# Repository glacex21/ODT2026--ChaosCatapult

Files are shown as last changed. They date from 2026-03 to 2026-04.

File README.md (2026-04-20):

# Open Design and Technology  
## Final Project README

> **Project Weight:** 70%  
> **Team Size:** 2 students  
> **Project Duration:** 4 weeks  
> **Class Time Available:** 6 hours per class  
> **Total Time Available:** 48 effort-hours per team  
> **Project Type:** Playful, interactive, technology-based experience

---

# Before you begin

## Fork and rename this repository
After forking this repository, rename it using the format:

`ODT-2026-TeamName`

### Example
`ODT-2026-PixelWizards`

Do not keep the default repository name.

---

# How to use this README

This file is your team’s **working project document**.

You must keep updating it throughout the 4-week build period.  
By the final review, this README should clearly show:
- your idea,
- your planning,
- your design decisions,
- your technical process,
- your build progress,
- your testing,
- your failures and changes,
- your final outcome.

## Rules
- Fill every section.
- Do not delete headings.
- If something does not apply, write `Not applicable` and explain why.
- Add images, screenshots, sketches, links, and videos wherever useful.
- Update task status and weekly logs regularly.
- Use this file as evidence of process, not only as a final report.

---

# 1. Team Identity

## 1.1 Studio / Group Name
`Group 15 - Chaos Catapult`

## 1.2 Team Members

| Name | Primary Role | Secondary Role | Strengths Brought to the Project |
|---|---|---|---|
| `Abhinav Akhare` | `Ideation/ Electronics / Coding / App / Mechanics` | `Fabrication` | `Strong understanding of mechanisms, hands-on prototyping, and integrating electronics with physical systems through iterative testing.` |
| `Riddhi Piratwad` | `-` | `-` | `-` |

## 1.3 Project Title
`Chaos Catapult`

## 1.4 One-Line Pitch
`A sensor-triggered, motorized catapult that combines controlled mechanics with unpredictable outcomes, creating a repeatable yet chaotic play experience.`

## 1.5 Expanded Project Idea
In 1–2 paragraphs, explain:
- what your project is,
- what kind of playful experience it creates,
- what makes it fun, curious, engaging, strange, satisfying, competitive, or delightful,
- what technologies are involved.

**Response:**  
`The Chaos Catapult is a motorized, sensor-driven kinetic system designed to transform simple user input into dynamic launch actions. The project is built around a seesaw-like catapult mechanism, where a controlled sequence of motor movements—combined with a gated release system—creates a repeatable launching process. An IR sensor detects user interaction, triggering a programmed sequence that rewinds, locks, and releases the mechanism, resulting in the projection of an object.
The experience is designed to be playful and engaging through the contrast between control and unpredictability. While the system operates through precise electronic and mechanical coordination, the outcome of each launch varies based on factors like weight, placement, and timing, making every interaction slightly different. This creates a sense of anticipation and satisfaction, encouraging repeated use. The project integrates multiple technologies, including an ESP32 microcontroller, DC and stepper motors for motion control, sensor-based triggering, and LED feedback, all working together to produce a responsive and interactive physical system.`

---

# 2. Philosophy Fit

## 2.1 Experience, Not Social Problem
This module does **not** require your project to solve a large social problem.

You are allowed to build:
- toys,
- games,
- interactive objects,
- playful machines,
- kinetic artifacts,
- humorous devices,
- strange but delightful experiences,
- things that are entertaining to use or watch.

## 2.2 What kind of experience are you creating?
Answer the following:
- What is the experience?
- What do you want the player or participant to feel?
- Why would someone want to try it again?

**Response:**  
`The project creates a playful, interactive experience centered around cause-and-effect, where a simple user action triggers a chain of mechanical and electronic responses leading to a launch. It functions as a kinetic, game-like object that invites users to engage with it physically and observe the outcome. The experience is less about winning or scoring and more about interaction, anticipation, and observing how the system responds.
The intended feeling is a mix of curiosity, anticipation, and satisfaction. Users experience a build-up as the system prepares to launch, followed by a sudden release, which creates a sense of excitement. Since the outcome of each launch can vary based on small changes in input—such as object placement or timing—the interaction feels unpredictable and slightly chaotic.
Users are encouraged to try it repeatedly because each interaction can produce a different result. This variability, combined with the satisfying mechanical motion and responsive feedback, makes the system engaging and replayable, turning a simple action into an enjoyable and dynamic experience.`

## 2.3 Design Persona
Complete the sentence below:

> We are designing this project as if we are a small creative studio making a **[toy / game / playable object / interactive experience]** for **[children / teens / adults / classmates / exhibition visitors / mixed audience]**.

**Response:**  
`We are designing this project as if we are a small creative studio making a playful, chaos-driven interactive object for classmates and exhibition visitors who like experimenting and figuring things out.`

---

# 3. Inspiration

## 3.1 References
List what inspired the project.

| Source Type | Title / Link | What Inspired You |
|---|---|---|
| `[Toy` | `Traditional Catapult / Trebuchet` | `Influenced the idea of launching objects through stored and released energy, creating a playful and physics-based interaction.` |
| `Game / Interaction` | `Arcade Trigger-Based Games` | `Inspired the simple input → action → response loop, where a user action immediately triggers a dynamic system reaction.` |

## 3.2 Original Twist
What makes your project original?

**Response:**  
`The project reinterprets a traditional catapult by shifting it from a purely manual mechanism to a partially automated, sensor-driven system. Instead of relying on direct human force, the interaction is mediated through a sequence of electronic and mechanical actions, including motorised actuation and controlled release through a gated mechanism. This introduces a layer of system logic between input and output, transforming a simple physical action into a multi-stage interactive process. What makes the project distinct is the combination of precise control and unpredictable outcomes. While the system is designed to operate through programmed sequences and controlled motion, the final result of each launch varies due to physical factors such as weight distribution, timing, and alignment. This tension between control and variability creates a unique play experience that blends engineered precision with emergent behaviour.`

---

# 4. Project Intent

## 4.1 Core Interaction Loop
Describe the main loop of interaction.

Examples:
- press → launch → score → reset
- connect → control → observe → repeat
- turn → trigger → react → repeat
- move object → sensor detects → sound/light response → player reacts

**Response:**  
`system ready → platform opens → weight drops → motor rewinds mechanism → IR sensor detects position → motor stops → gate closes to hold weight → motor releases (launch action) → system resets to initial state → repeat`

## 4.2 Intended Player / Audience

| Question | Response |
|---|---|
| Who is this for? | `Students & Peers` |
| Age range | `12+` |
| Solo or multiplayer | `Primarily solo, but can be observed and enjoyed by multiple people` |
| Expected duration of one round | `10-15 seconds per cycle` |
| What should the player feel? | `Curiosity, anticipation, and satisfaction from the launch action` |
| Is explanation required before use? | `Minimal explanation required; interaction is mostly intuitive with basic guidance` |

## 4.3 Player Journey
Describe exactly how a player will use the project.

1. **Approach:** `The player approaches the setup, noticing the catapult mechanism and multiple target cups placed at increasing distances.`
2. **Start:** `The player connects to the system through the app and prepares the catapult for use.`
3. **First Action:** `The player places a ball on the platform and uses the app to trigger the system.`
4. **Main Interaction:** `The system runs its sequence—opening the platform, rewinding the mechanism, and preparing for launch—while the player observes and anticipates the outcome.`
5. **System Response:** `The mechanism releases, launching the ball toward the target. The result varies based on placement, timing, and system dynamics.`
6. **Win / Lose / End Condition:** `If the ball lands in the target cup, the player successfully completes that level. If the player misses, they must move the catapult forward (using the wheeled base) to attempt the next target at a different distance.`
7. **Reset:** `The system resets to its initial state, allowing the player to reposition, place another ball, and attempt the next level.`

## 4.4 Rules of Play
If your project is a game, list the rules clearly.

- `The player must place a ball on the catapult platform before triggering the system.`
- `The system can only be activated through the app once the setup is ready.`
- `The objective is to land the ball inside the target cup.`
- `If the player misses, they must reposition the catapult using the wheeled base and attempt the next level.`
 - `Each successful shot allows progression to a farther or more challenging target.`
 - `The system must complete its full cycle (launch and reset) before the next attempt begins.`
---

# 5. Definition of Success

## 5.1 Definition of “Playable”
Your project will be considered complete only if these conditions are met.

- [x] `[The system responds to user input (app or sensor) and initiates the sequence]`
- [x] `[he mechanical system is able to perform the launch action]`
- [ ] `[The motor-driven rewind and release mechanism functions with partial or full consistency]`
- [x] `[The gate mechanism successfully controls the holding and release of the object]`
- [ ] `[The system is able to reset to an initial or near-initial state for repeated interaction]`

## 5.2 Minimum Viable Version
What is the smallest version of this project that still delivers the core experience?

**Response:**  
`The minimum viable version of the project focuses on achieving a partially automated interaction where the system responds to input and executes key stages of the sequence, even if the final actuation is inconsistent.

In this version, components such as sensor detection, sequencing logic, and control of intermediate stages like gate movement function as intended, demonstrating the designed interaction flow. However, the main motor-driven launch may not perform reliably due to hardware limitations.

This still allows the core idea of a staged, system-driven interaction to be understood, where user input triggers a chain of mechanical and electronic responses, even if the final output is not fully realized.`

## 5.3 Stretch Features
What features are nice to have but not essential?

- `Automated scoring system to track successful shots into the target`
- `Adjustable launch power or angle control through the app`
- `Multiple difficulty levels with dynamic target positions or distances`
---

# 6. System Overview

## 6.1 Project Type
Check all that apply.

- [x] Electronics-based
- [x] Mechanical
- [x] Sensor-based
- [x] App-connected
- [x] Motorized
- [ ] Sound-based
- [ ] Light-based
- [ ] Screen/UI-based
- [x] Fabricated structure
- [x] Game logic based
- [x] Installation / tabletop experience
- [ ] Other: `[Write here]`

## 6.2 High-Level System Description
Explain how the system works in simple terms.

Include:
- input,
- processing,
- output,
- physical structure,
- app interaction if any.

**Response:**  
`The project is a multi-stage interactive system that combines electronics, mechanical movement, and programmed logic to create a controlled launching mechanism. At its core, the system is designed so that a simple user input triggers a sequence of coordinated actions rather than a single direct response.
The interaction begins when the system receives input, either through an IR sensor detecting the presence or position of an object, or through a mobile app used to initiate the sequence. This input is processed by the ESP32 microcontroller, which acts as the central control unit. Based on the programmed logic, the ESP32 executes a step-by-step sequence that coordinates multiple components instead of activating them all at once. The system output is achieved through a combination of motors and visual feedback. A stepper motor controls the opening and closing of a gate mechanism, which determines when the object is held or released. A DC motor drives the rewind and release motion of the catapult, creating the force required for launching. LEDs are used to communicate system states, such as readiness, active motion, and completion, helping the user understand what stage the system is in. Physically, the project is built as a wheeled catapult structure with a pivot-based mechanism. The platform holds the object initially, and through the sequence of actions, the object is repositioned and eventually launched. The inclusion of wheels allows the entire system to be repositioned in space, enabling different levels or target distances as part of the gameplay.
The mobile app acts as an interface layer between the user and the system, allowing control over when the sequence begins and potentially adjusting how the system behaves. Overall, the project integrates input, processing, and output into a coordinated system where mechanical movement and electronic control work together to produce a dynamic and repeatable interaction.`

## 6.3 Input / Output Map

| System Part | Type | What It Does |
|---|---|---|
| IR Sensor | Input | Detects the presence or position of the weight/ball and signals the system to proceed with the sequence |
| Mobile App | Input | Allows the user to trigger and control the system remotely |
| ESP32 | Processing | Acts as the central controller, executing the programmed sequence and coordinating all components |
| Step-Up Converter  | Processing / Power | Regulates and boosts voltage to provide sufficient power for motors, ensuring stable operation |
| Motor Driver | Processing / Control | Interfaces between ESP32 and motors, controlling direction and power delivery |
| DC Motor | Output | Drives the rewind and release mechanism responsible for the launching action |
| Stepper Motor | Output | Controls precise opening and closing of the gate mechanism |
| LEDs | Output | Provide visual feedback for system states (ready, active, rewinding, reset) |
| Catapult Mechanism | Physical Action | Converts rotational motion into a launching force through a pivot-based system |
| Gate Mechanism | Physical Action | Holds and releases the object at the correct stage of the sequence |
| Wheeled Base | Physical Action | Allows repositioning of the system for level-based gameplay | NEMA 17 Stepper Motor | Output | Provides precise control for rewind and release |

---

# 7. Sketches and Visual Planning

## 7.1 Concept Sketch
Add an early sketch of the full idea.

**Insert image below:**  
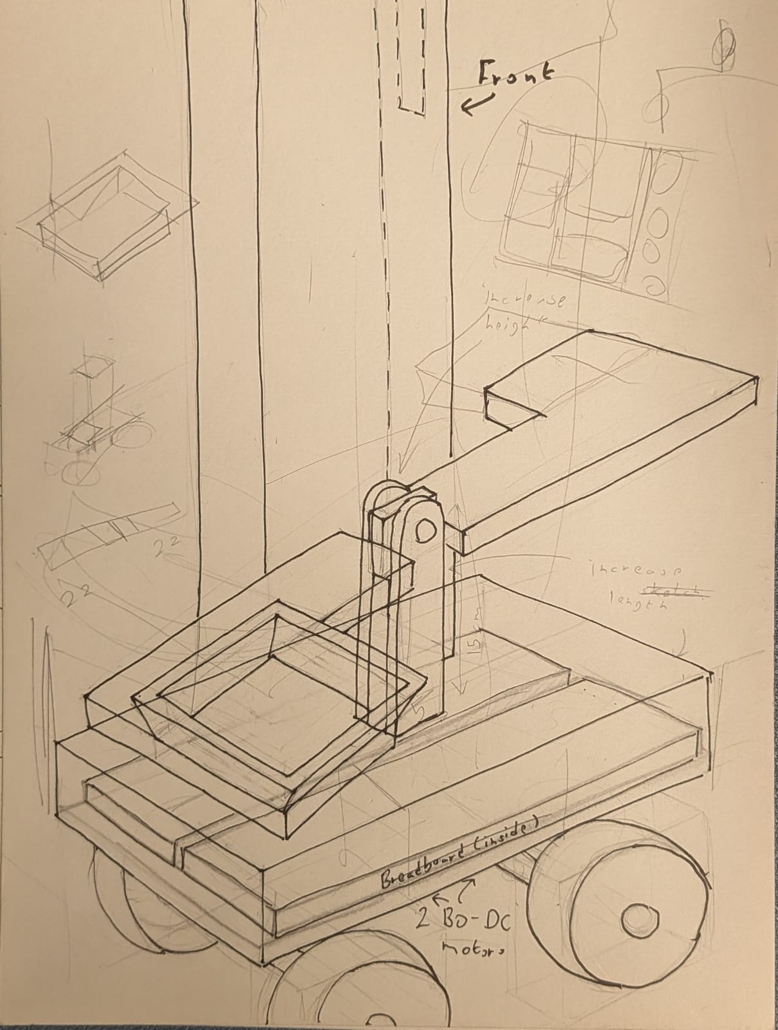
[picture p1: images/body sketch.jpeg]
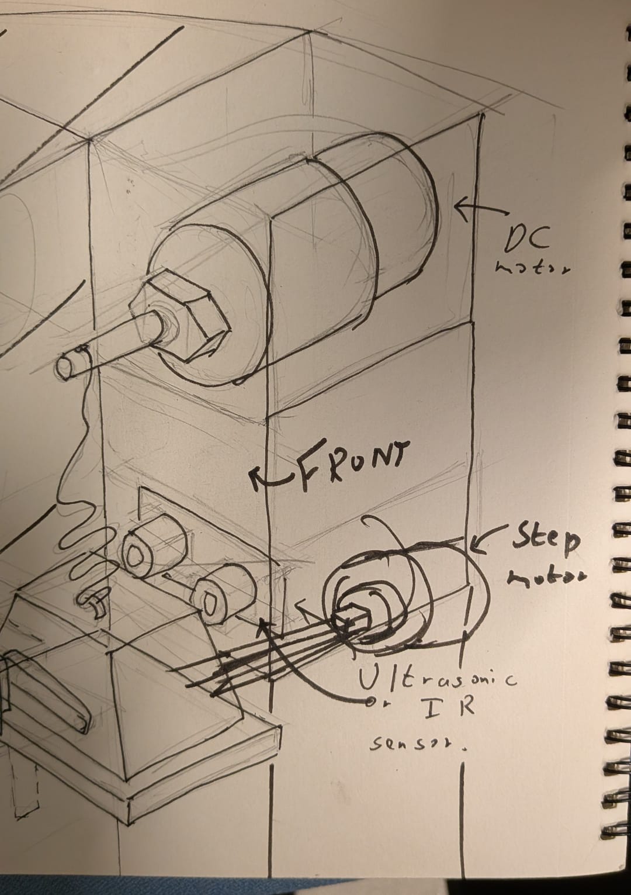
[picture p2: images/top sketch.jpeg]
 

## 7.2 Labeled Build Sketch
Add a sketch with labels showing:
- structure,
- electronics placement,
- user touch points,
- moving parts,
- output elements.

**Insert image below:**  
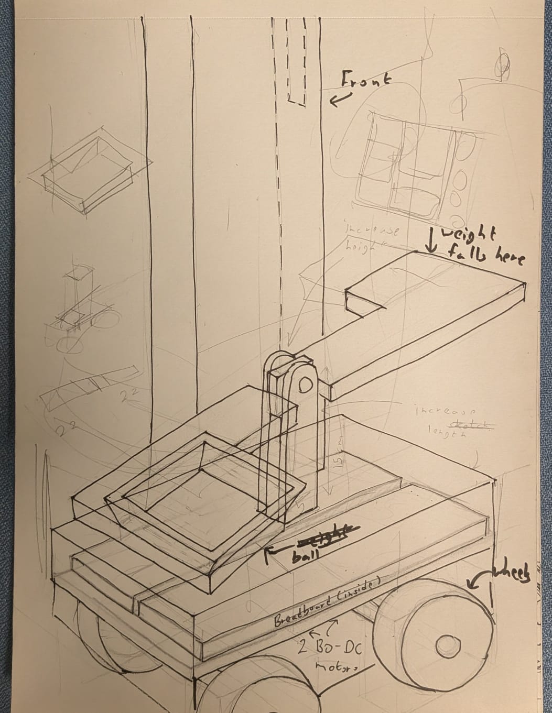
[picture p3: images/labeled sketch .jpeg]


## 7.3 Approximate Dimensions

| Dimension | Value |
|---|---|
| Length | `40cm` |
| Width | `[25cm]` |
| Height | `[50cm]` |
| Estimated weight | `[400-500gms]` |

---

# 8. Mechanical Planning

## 8.1 Mechanical Features
Check all that apply.

- [ ] Gears
- [x] Pulleys
- [ ] Belt drives
- [ ] Linkages
- [x] Hinges
- [x] Shafts
- [ ] Springs
- [ ] Bearings
- [x] Wheels
- [ ] Sliders
- [x] Levers
- [ ] Not applicable

## 8.2 Mechanical Description
Describe the mechanism and what it is meant to do.

**Response:**  
`[The mechanical system is based on a lever-driven catapult mechanism, where a pivot point allows rotational motion to be converted into a launching action. A platform holds the object initially, and through controlled movement, the system transfers force to propel the object forward.
A pulley system is integrated with the motor to lift and rewind the weight. As the motor rotates, the pulley winds a string or linkage, pulling the mechanism into a loaded position. This allows energy to be stored and later released during the launch phase.
A gate mechanism is used to control when the object is released. This gate is actuated using a stepper motor, allowing precise opening and closing at specific stages of the sequence.
During development, the initial DC motor showed inconsistent performance during the rewind stage, including irregular motion and unreliable operation under load. To address this, a NEMA 17 stepper motor was introduced as an alternative, as it provides better control and more consistent torque for lifting and positioning the mechanism.
The entire system is mounted on a wheeled base, allowing it to be repositioned for different target distances and levels. The combination of lever mechanics, pulley-based lifting, and motor-driven control creates a staged and interactive mechanical system.]`

## 8.3 Motion Planning
If something moves, explain:
- what moves,
- what causes the movement,
- how far it moves,
- how fast it moves,
- what could go wrong.

**Response:**  
`The main moving parts are the catapult arm, the pulley system, the gate, and the wheels. The catapult arm rotates around a pivot to create the launch. The pulley system lifts the weight during rewind, and the gate opens and closes to control when the object is released. The wheels allow the system to move forward and backward for positioning.
The movement is caused by motors. A DC motor is used for the rewind and release mechanism through the pulley, while a NEMA 17 stepper motor was tested as an alternative. A separate stepper motor controls the gate movement. BO DC motors are used to drive the wheels for movement.
The gate moves roughly 90°, and the catapult arm moves through a small arc to generate the launch. The rewind motion is slower and controlled, while the release is faster to create force. Wheel movement is continuous and depends on motor input.
Possible issues include low torque in the DC motor during rewind, insufficient performance from the NEMA setup, pulley misalignment, stepper jamming, and instability due to weight during movement. These issues affected the consistency of the full sequence.`

## 8.4 Simulation / CAD / Animation Before Making
If your project includes mechanical motion, document the digital planning before fabrication.

| Tool Used | File / Link | What Was Tested |
|---|---|---|
| `Not Applicable]` | `-` | `[No simulation or animation was performed; the mechanism was developed through physical prototyping and testing` |

## 8.5 Changes After Digital Testing
What changed after the CAD, animation, or simulation stage?

**Response:**  
`Not applicable, as no digital simulation was used. Changes were made directly through physical testing and iteration during the build process.`

---

# 9. Electronics Planning

## 9.1 Electronics Used

| Component | Quantity | Purpose |
|---|---:|---|
| ESP32 | 1 | Main controller to process input and control the system |
| IR Sensor | 1 | Detects the presence/position of the object |
| BO DC Motors | 2 | Drive the wheels for movement of the system |
| DC Motor | 1 | Drives the rewind mechanism for lifting the weight |
| NEMA 17 Stepper Motor | 1 | Tested as an alternative for the rewind mechanism |
| Stepper Motor (Gate) | 1 | Controls opening and closing of the gate |
| Motor Drivers (L298N) | 2 | Control motor direction and power delivery |
| Step-Up Converters | 2 | Boost voltage (5V to ~8V) for motors |
| LEDs (Red & Green) | 2 | Provide visual feedback for system states |
| Power Bank | 1 | Supplies power to the entire system |

## 9.2 Wiring Plan
Describe the main electrical connections.

**Response:**  
`The system is powered using a power bank, which was modified to supply power through a step-up converter. The output from the step-up converter is connected to the power rails, which distribute power to the motors and other components.
The ESP32 is also powered through the power rails. A resistor-based connection is used along with a GPIO pin (keep_alive) to keep the power bank active continuously and prevent it from shutting off due to low current draw.
The IR sensor is connected to the ESP32, with power from the 3.3V pin and its output connected to a GPIO pin for input detection.
Motor control is handled using L298N motor drivers. The ESP32 is connected to the input pins (IN1, IN2, etc.) of the motor drivers to control motor direction. The enable pins are kept active or controlled via PWM depending on the requirement. One driver is used for the DC motor (and later testing with the NEMA 17), and another is used for additional motor control.
The motors are connected to the output terminals of the motor drivers, which receive power from the step-up converter to ensure sufficient voltage for operation under load.
LEDs are connected to GPIO pins on the ESP32 with resistors to provide visual feedback for different system states.
All components share a common ground through the power rails, ensuring stable communication and proper functioning of the system.`

## 9.3 Circuit Diagram
Insert a hand-drawn or software-made circuit diagram.

**Insert image below:**  
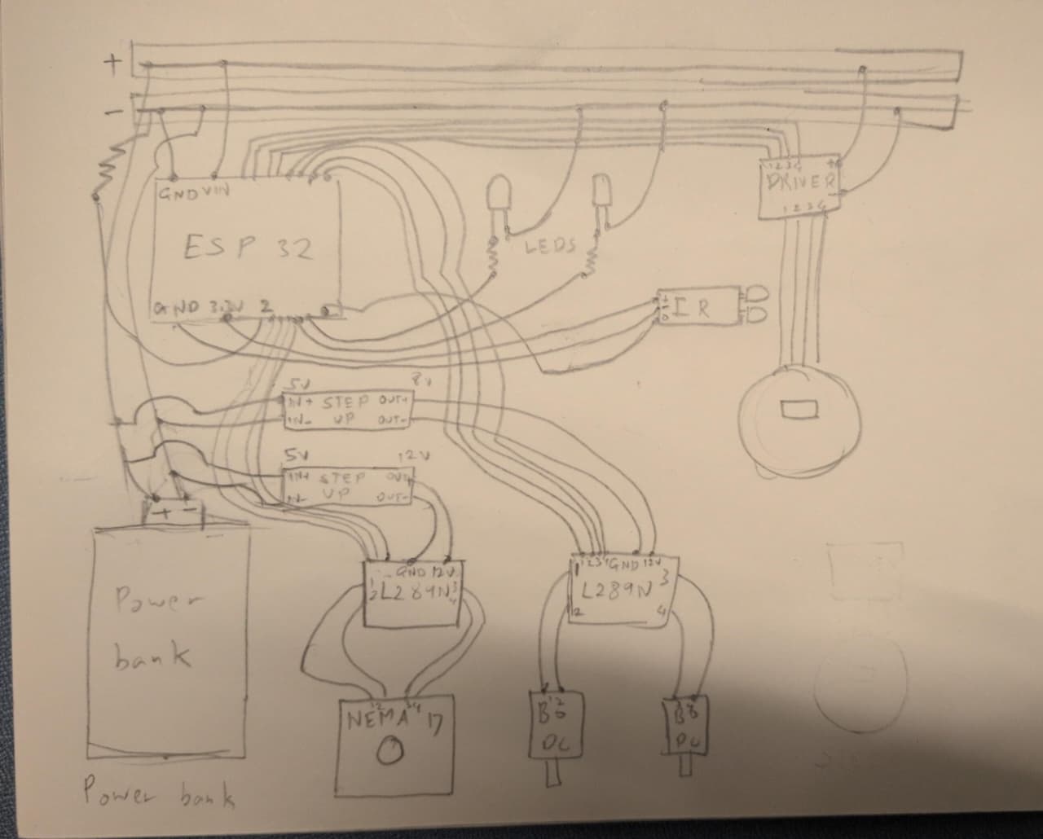
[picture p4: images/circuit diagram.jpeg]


## 9.4 Power Plan

| Question | Response |
| --- | --- |
| Power source | Power bank (USB-based) |
| Voltage required | 5V from power bank, stepped up to ~8V for motors using step-up converters |
| Current concerns | DC motor (used for rewind) and NEMA motor draw high current under load; BO DC motors for wheels also add load, causing unstable performance |
| Safety concerns  | Risk of overheating in motors and drivers, unstable voltage from converters, and loose wiring affecting reliability |

# 10. Software Planning

## 10.1 Software Tools

| Tool / Platform | Purpose |
| Tool / Platform                    | Purpose                                                                 |
| ---------------------------------- | ----------------------------------------------------------------------- |
| MicroPython                        | Used to program the ESP32 and control sensors, motors, and system logic |
| MIT App Inventor                   | Used to create a mobile app for triggering and controlling the system   |
|Thonny | Used to write, upload, and test code on the ESP32                       |

## 10.2 Software Logic
Describe what the code must do.

Include:
- startup behavior,
- input handling,
- sensor reading,
- decision logic,
- output behavior,
- communication logic,
- reset behavior.

**Response:**  
`The system is programmed using MicroPython on the ESP32 and follows a stage-based logic controlled through a mobile app.
At startup, all pins are initialized for motors, LEDs, and sensors, and the ESP32 connects to the app. The user sends commands like calibration, drop, close, rewind, and unwind through the app.
The system first runs in a manual calibration mode, where the gate position is adjusted using left/right controls. Once set, a “done” command locks the position.
After calibration, the system follows a sequence. A drop command opens the gate using the stepper motor. Then the rewind stage starts, where the mechanism is pulled back. In the DC motor version, this is done using continuous motor rotation, while in the NEMA stepper version, controlled stepping is used.
In the NEMA version, the rewind continues until the IR sensor detects the correct position, at which point the motor stops. This adds more control compared to the DC motor version.
A close command then shuts the gate to hold the weight. Finally, the unwind stage releases the stored energy, creating the launch action.
LEDs are used throughout to show system states like active movement, rewinding, and completion.
The system runs in a loop, constantly checking for app inputs and updating its state, allowing repeated cycles of interaction.`

## 10.3 Code Flowchart
Insert a flowchart showing your code logic.

Suggested sequence:
- start,
- initialize,
- wait for input,
- read input,
- decision,
- trigger output,
- repeat or reset,
- error handling.

**Insert image below:**  
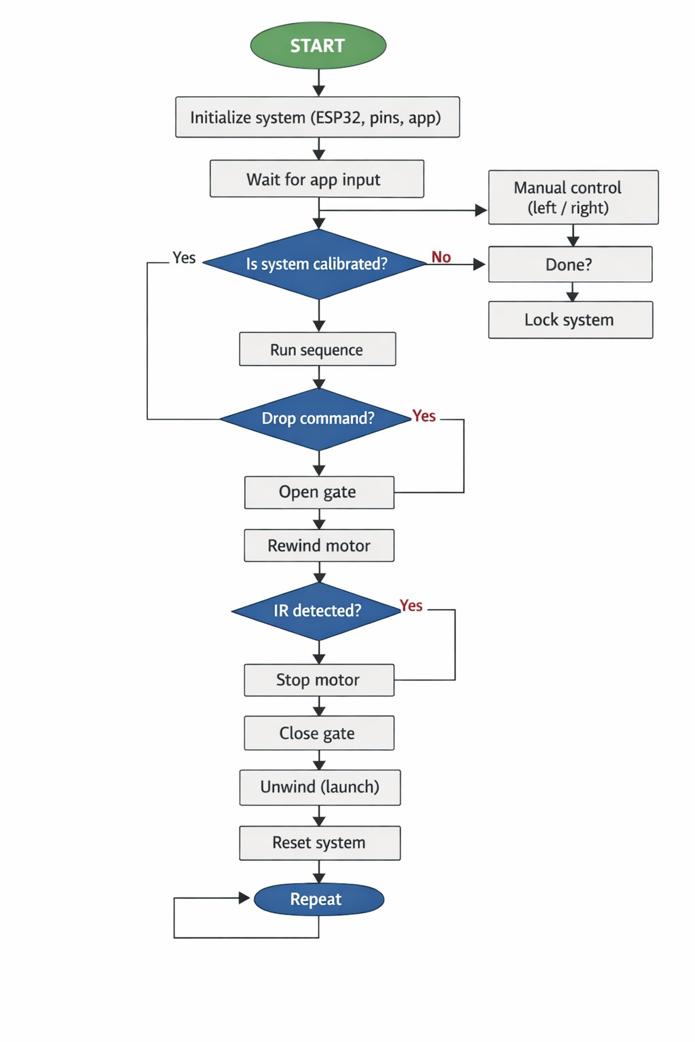
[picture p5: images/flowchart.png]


## 10.4 Pseudocode

```text
START

Initialize system (ESP32, pins, app)

WHILE true:
    Check for app input

    IF not calibrated:
        Allow manual gate control (left/right)
        IF user presses done:
            lock system

    ELSE:
        IF drop command:
            open gate

        IF rewind active:
            run motor
            IF IR detects position:
                stop motor

        IF close command:
            close gate

        IF unwind active:
            release mechanism (launch)

    Update LEDs based on state

END LOOP
```

---

# 11. MIT App Inventor Plan

## 11.1 Is an app part of this project?
- [x] Yes
- [ ] No

If yes, complete this section.

## 11.2 Why is the app needed?
Explain what the app adds to the experience.

Examples:
- remote control,
- score tracking,
- mode selection,
- personalization,
- triggering effects,
- displaying data.

**Response:**  
`The app is used to control and trigger the system wirelessly, allowing the user to interact with the catapult without directly touching the hardware. It enables actions such as calibration, opening and closing the gate, and controlling the rewind and release stages.
The app also allows movement control, enabling the system to move forward and backward for different levels or target distances. This adds flexibility to the interaction and supports the gameplay aspect.
Using the app makes the interaction more controlled and intuitive, as all actions are managed through a single interface instead of multiple physical inputs.`

## 11.3 App Features

| Feature | Purpose |
| --- | --- |
| Left / Right Control | Used during calibration to adjust gate position |
| Done Button | Locks the system after calibration is complete |
| Drop Button | Triggers opening of the gate to release the object |
| Close Button | Closes the gate to hold the object in place |
| Rewind Button | Activates motor to pull the mechanism back |
| Unwind Button | Releases the mechanism to perform the launch |
| Stop Button | Stops motor movement when required |
| Forward / Backward Control | Moves the system for level-based gameplay |

## 11.4 UI Mockup
Insert a sketch or screenshot of the app interface.

**Insert image below:**  
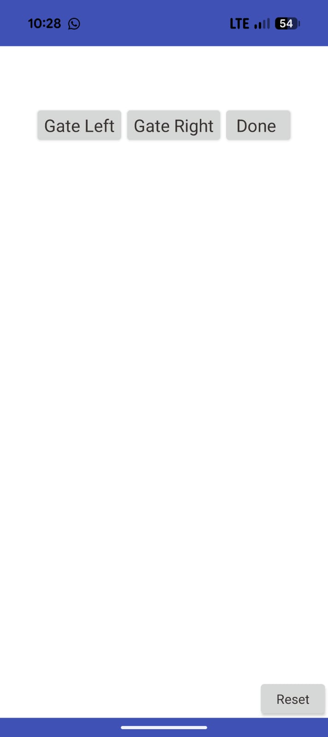
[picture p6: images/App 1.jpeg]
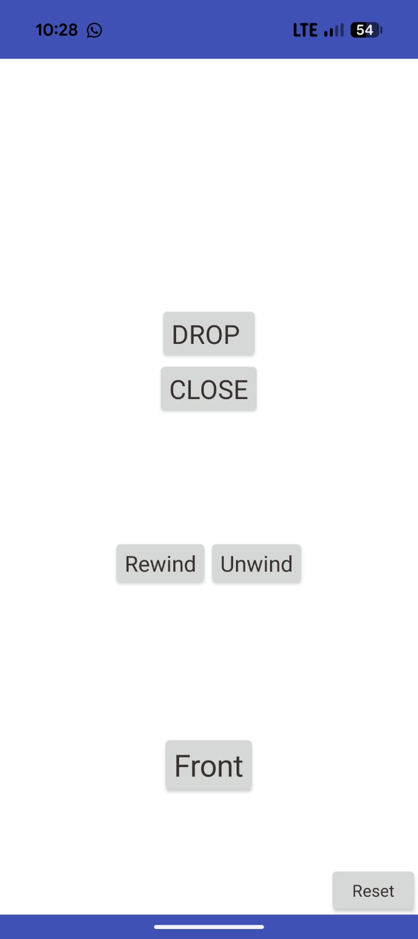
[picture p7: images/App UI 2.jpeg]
 

## 11.5 App Screen Flow

1. Open the app and access the control interface
2. Use left/right controls to calibrate the gate position
3. Press “Done” to lock the system in place
4. Use buttons like drop, rewind, close, and unwind to run the sequence
5. Use forward/backward controls to reposition the system for different levels
6. Repeat the process for each attempt
---

# 12. Bill of Materials

## 12.1 Full BOM

| Item | Quantity | In Kit? | Need to Buy? | Estimated Cost | Material / Spec | Why This Choice? |
| --- | ---: | --- | --- | ---: | --- | --- |
| ESP32 | 1 | Yes | No | 0 | Microcontroller | Main controller for system logic |
| IR Sensor | 1 | Yes | No | 0 | Digital sensor | Detects object position |
| DC Motor | 2 | No | Yes | ₹150 | Standard DC motor | Used for rewind and motion |
| NEMA 17 Stepper Motor | 1 | Yes | No | 0 | Stepper motor | Tested for better torque and control |
| Stepper Motor (Gate)  | 1 | Yes | No | 0 | Stepper motor | Controls gate opening/closing |
| L298N Motor Driver | 2 | Yes | No | 0 | Motor driver module | Controls motor direction and power |
| Step-Up Converter | 1 | No | Yes | ₹100 | Voltage booster | Provides sufficient voltage to motors |
| Wheels | 2–4 | No | Yes | ₹150 | Plastic wheels | Enables movement for level-based gameplay |
| LEDs | 2 | Yes | No | 0 | Red & Green LEDs | Visual feedback |
| Resistors | Few | Yes | No | 0 | Standard | Used for LEDs and keep-alive circuit |
| Power Bank | 1 | Yes | No | 0 | 5V output | Main power source |
| Wires / Connectors | Many | Yes | No | 0 | Jumper wires | Electrical connections |
| Structural Material | — | Yes | No | 0 | MDF / board | Physical structure |
| NEMA 17 Stepper Motor | 1 | No | Yes | ₹500 | Stepper motor | Purchased as a replacement due to DC motor performance issues |

## 12.2 Material Justification
Explain why you selected your main materials and components.

Examples:
- Why acrylic instead of cardboard?
- Why MDF instead of 3D print?
- Why servo instead of DC motor?
- Why bearing instead of a plain shaft hole?

**Response:**  
`The main structure of the project is made using MDF and wood as they are strong, easily available, and suitable for building stable mechanical systems. These materials are easy to cut, assemble, and modify during testing, which was important for iterative prototyping.
MDF provides a flat and rigid surface for mounting components, while wood adds additional strength to areas requiring support. Compared to materials like cardboard, they offer better durability and can handle the load and movement of motors and the catapult mechanism.`

## 12.3 Items to Purchase Separately

| Item | Why Needed | Purchase Link | Latest Safe Date to Procure | Status |
| --- | --- | --- | --- | --- |
| DC Motors | For rewind and movement mechanism | — | Week 2 | Received |
| Step-Up Converter | To provide sufficient voltage for motors | — | Week 2 | Received |
| Wheels | To enable movement for level-based gameplay | — | Week 2 | Received |
| NEMA 17 Stepper Motor | Emergency purchase to replace DC motor due to performance issues | — | Week 4 | Received |

## 12.4 Budget Summary

| Budget Item | Estimated Cost |
| --- | ---: |
| Electronics | ₹650 |
| Mechanical parts | ₹150 |
| Fabrication materials | ₹100 |
| Purchased extras | ₹0 |
| Contingency | ₹0 |
| **Total** | **₹900** |

## 12.5 Budget Reflection
If your cost is too high, what can be simplified, removed, substituted, or shared?

**Response:**  
`Most of the components were selected appropriately for the project, but the main challenge was with motor performance. The emergency purchase of the NEMA 17 stepper motor increased the overall cost but did not fully resolve the issue.
In hindsight, a better motor driver or power management setup for the DC motor could have been a more effective solution instead of replacing the motor entirely. This highlights the importance of selecting the right control and power components early in the design process.`

---

# 13. Planning the Work

## 13.1 Team Working Agreement
Write how your team will work together.

Include:
- how tasks are divided,
- how decisions are made,
- how progress will be checked,
- what happens if a task is delayed,
- how documentation will be maintained.

**Response:**  
`The project was initially planned with different parts like mechanics, electronics, and coding. However, since all these parts were closely connected, most of the work was handled together to keep the system consistent.
Work was done through continuous testing and iteration. Decisions were made based on what worked during testing, and changes were made accordingly.
Progress was tracked by testing different parts of the system and updating the documentation alongside the build. Any issues or delays were handled during the process by adjusting the approach and trying alternative solutions.`

## 13.2 Task Breakdown

| Task ID | Task | Owner | Estimated Hours | Deadline | Dependency | Status |
| --- | --- | --- | ---: | --- | --- | --- |
| T1 | Finalize concept and interaction | Abhinav Akhare | 3 | Week 1 | None | Done |
| T2 | Create sketches and design planning | Abhinav Akhare | 4 | Week 1 | T1 | Done |
| T3 | Source components and finalize BOM  | Abhinav Akhare | 2 | Week 1 | T1 | Done |
| T4 | Test electronics (motors, sensors)  | Abhinav Akhare | 6 | Week 2 | T3 | Done |
| T5 | Build mechanical structure | Abhinav Akhare | 8 | Week 2 | T2 | Done |
| T6 | Develop and test control code | Abhinav Akhare | 10 | Week 3 | T4 | Done |
| T7 | Integrate system (hardware + code)  | Abhinav Akhare | 8 | Week 3 | T5, T6 | Done |
| T8 | Debug and refine system | Abhinav Akhare | 5 | Week 4 | T7 | Done |
| T9 | Documentation and final updates | Abhinav Akhare | 4 | Week 4 | T8 | In Progress |

## 13.3 Responsibility Split

| Area | Main Owner | Support Owner |
| --- | --- | --- |
| Concept and gameplay | Abhinav Akhare | — |
| Electronics | Abhinav Akhare | — |
| Coding | Abhinav Akhare | — |
| App | Abhinav Akhare | — |
| Mechanical build | Abhinav Akhare | — |
| Testing | Abhinav Akhare | — |
| Documentation | Abhinav Akhare | — |

---

# 14. Weekly Milestones

## 14.1 Four-Week Plan

### Week 1 — Plan and De-risk
Expected outcomes:
- [x] Idea finalized
- [ ] Core interaction decided
- [x] Sketches made
- [x] BOM completed
- [x] Purchase needs identified
- [x] Key uncertainty identified
- [ ] Basic feasibility tested

### Week 2 — Build Subsystems
Expected outcomes:
- [x] Electronics tests completed
- [x] CAD / structure planning completed
- [ ] App UI started if needed
- [x] Mechanical concept tested
- [x] Main subsystems partially working

### Week 3 — Integrate
Expected outcomes:
- [x] Physical body built
- [x] Electronics integrated
- [x] Code connected to hardware
- [ ] App connected if required
- [ ] First playable version exists

### Week 4 — Refine and Finish
Expected outcomes:
- [ ] Technical bugs reduced
- [ ] Playtesting completed
- [ ] Improvements made
- [x] Documentation completed
- [x] Final build ready

## 14.2 Weekly Update Log

| Week | Planned Goal | What Actually Happened | What Changed | Next Steps |
| --- | --- | --- | --- | --- |
| Week 1 | Finalize idea and planning | Idea and overall interaction were finalized; initial direction was clear | Focus was more on concept than detailed technical planning  | Begin building structure and gather components |
| Week 2 | Build and test subsystems  | Mechanical structure was developed and components were organized | Electronics setup was planned but not fully implemented yet | Start electronics integration and coding |
| Week 3 | Integration and coding | Coding and wiring were developed, and initial system integration was attempted | Motor behavior required further tuning and testing | Improve motor control and refine system |
| Week 4 | Final build and testing | Major system integration, coding updates, and component adjustments (including NEMA) were completed | Adjustments were made to improve performance and control | Finalize documentation and system explanation  |

---

# 15. Risks and Unknowns

## 15.1 Risk Register

| Risk | Likelihood | Impact | Mitigation / Response |
| --- | --- | --- | --- |
| DC motor not providing enough torque | High | High | Issue identified during testing; replacement with NEMA motor attempted late |
| NEMA motor driver not handling load properly | High | High | Limited time for proper tuning; basic testing done |
| Stepper motor jamming during operation | Medium | High | Observed during testing; likely due to alignment/load issues |
| IR sensor giving inconsistent readings | Medium | Medium | Position adjusted but readings remained unreliable |
| Wheels unable to support system weight | Medium | Medium | Movement was reduced to avoid overload |
| Power supply instability (power bank limits) | High | High | Step-up converter and keep-alive used, but limitations remained |
| Timing mismatch between stages | Medium | Medium | Minor adjustments in code, but full synchronization not achieved |
| Integration issues between components | High | High | Integration attempted late; limited time for full debugging |
| Platform shape causing instability and misalignment | Medium | High | Iterated on shape during build, but consistent alignment was difficult to achieve |

## 15.2 Biggest Unknown Right Now
What is the single biggest uncertainty in your project at this stage?

**Response:**  
`One of the main failures in the system was the rewind mechanism. Both the DC motor and later the NEMA 17 stepper motor struggled to pull the weight effectively through the pulley system. The DC motor showed inconsistent behavior and lacked sufficient torque under load, which caused unreliable movement.
To address this, a NEMA 17 motor was introduced, but it also faced issues due to driver limitations and insufficient torque delivery in the given setup. As a result, the system was unable to consistently lift and position the weight for the launch sequence.
Additional issues included the stepper motor jamming at times, inconsistent readings from the IR sensor, and instability caused by the shape of the platform, which affected alignment. The wheels also faced difficulty supporting the overall load during movement.
These failures highlighted challenges in motor selection, load handling, and overall system integration.`

---

# 16. Testing and Playtesting

## 16.1 Technical Testing Plan

| What Needs Testing | How You Will Test It | Success Condition |
| --- | --- | --- |
| App connection (WiFi/App link) | Connect phone to ESP32 network and send commands from app | Commands are received and printed/responded correctly |
| Mechanism movement | Run motors (DC/NEMA and stepper) through app commands | Motors move in correct direction and complete intended motion |
| Sensor behavior (IR) | Place/remove object in front of sensor and monitor response | Sensor reliably detects presence/absence and triggers logic |
| App communication | Send actions like drop, close, rewind, unwind from app | System responds correctly to each command without delay |

## 16.2 Playtesting Plan

| Question | How You Will Check |
| --- | --- |
| Do players understand what to do? | Observe if users can place the ball correctly and use the app controls (drop, rewind, close) without detailed instructions |
| Is the interaction satisfying? | Observe reactions during the launch attempt, especially the rewind → release sequence |
| Do players want another turn? | Check if users try to adjust position (using wheels) and attempt again after missing the target |
| Is the challenge balanced? | Test different distances of the cup and see if users can reasonably aim using repositioning |
| Is the response clear and immediate? | Observe if users understand system states through motor movement and LED feedback during each stage |

## 16.3 Testing and Debugging Log

| Date | Problem Found | Type | What You Tried | Result | Next Action |
| --- | --- | --- | --- | --- | --- |
| Week 4 | DC motor unable to pull weight consistently | Technical | Increased voltage using step-up converter and reduced load | Partly | Look into stronger motor option |
| Week 3 | IR sensor giving inconsistent readings | Technical | Adjusted sensor placement and tested multiple times | Partly | Improve positioning and stability |
| Week 4 | Stepper motor jamming during movement | Mechanical  | Checked alignment and reduced friction in mechanism | Partly | Refine alignment and reduce resistance |
| Week 3 | Wheels unable to support system weight | Mechanical  | Tested movement with reduced load | Partly | Improve wheel support or reduce weight |
| Week 4 | NEMA motor introduced but driver struggled under load | Technical | Tested NEMA with existing driver setup | Failed | Explore better driver or alternative setup |
| Post-exhibition | Full system integration not stable | Integration | Tested components individually and reviewed sequence | Partly | Improve power management and synchronization |

## 16.4 Playtesting Notes

| Tester  | What They Did | What Confused Them | What They Enjoyed | What You Will Change |
| --- | --- | --- | --- | --- |
| Baratth | Tried to operate the system and place the ball for launch | Had difficulty understanding how to correctly set and calibrate the gate position | Liked the idea of launching towards a target | Simplify the gate calibration process and make it more intuitive |

---

# 17. Build Documentation

## 17.1 Fabrication Process
Describe how the project was physically made.

Include:
- cutting,
- 3D printing,
- assembly,
- fastening,
- wiring,
- finishing,
- revisions.

**Response:**  
`The fabrication process started with a rough foam model to understand the proportions and basic working of the mechanism. This helped in figuring out the placement of components and overall structure before moving to final materials.
Based on this, measurements were taken alongside ideation and the main parts were laser cut using MDF. During assembly in the wood lab, several adjustments were made to improve alignment and fit, especially for the pivot and pulley system.
The structure was assembled using basic fastening methods like screws and joints. Some components, such as axle caps, were 3D printed to support the wheel mechanism and ensure proper fitting.
Electronics were integrated after the basic structure was ready. Wiring was done using power rails, with the power bank connected through a step-up converter. The power bank was modified and connected in a way that allowed continuous supply using a keep-alive setup.
Multiple revisions were made during the build process, especially to adjust alignment, improve movement, and integrate the motors properly. Final finishing involved securing components, organizing wiring, and making the system stable for testing.`

## 17.2 Build Photos
Add photos throughout the project.

Suggested images:
- early sketch,
- prototype,
- electronics testing,
- mechanism test,
- app screenshot,
- final build.

Example:
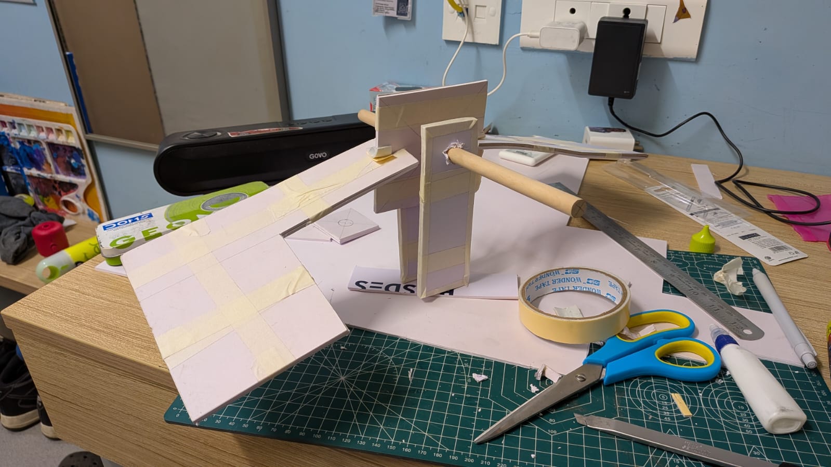
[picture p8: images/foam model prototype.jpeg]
 
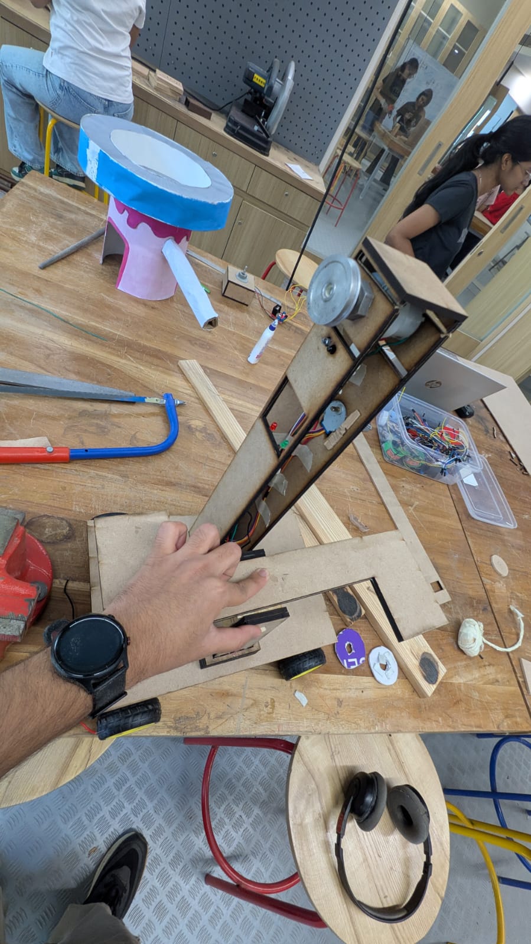
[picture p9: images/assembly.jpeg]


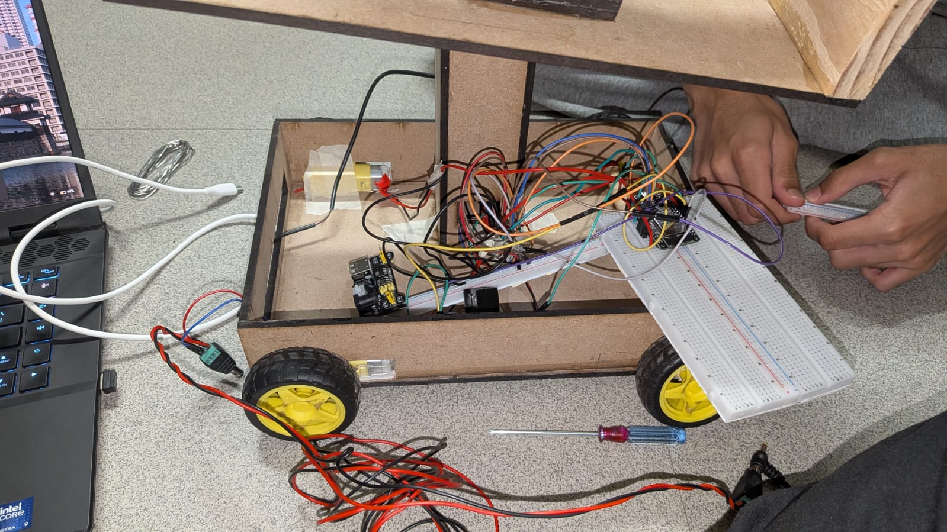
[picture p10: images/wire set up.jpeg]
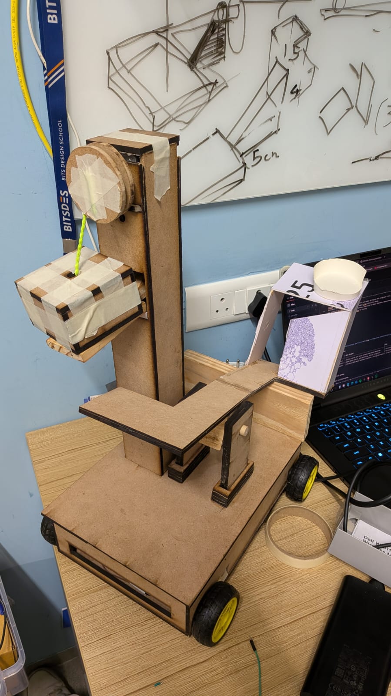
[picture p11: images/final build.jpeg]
 

## 17.3 Version History

| Version | Date | What Changed | Why |
| --- | --- | --- | --- |
| `v1` | Week 1 | Initial concept with basic catapult and manual mechanism | To establish core idea and interaction |
| `v2` | Week 2–3 | Added motor control, gate mechanism, and app integration | To automate the system and improve interaction |
| `v3` | Week 4 | Introduced NEMA motor and made structural + wiring adjustments | To address motor performance issues and improve load handling |

---

# 18. Final Outcome

## 18.1 Final Description
Describe the final version of your project.

**Response:**  
`The final version of the project is a motor-driven catapult system controlled through an app, combining a gate mechanism, pulley-based rewind system, and sensor-based logic. The system is designed to follow a sequence where the gate opens, the mechanism rewinds, and then releases to launch an object.
While individual parts like the app control, gate movement, and basic motor responses worked, the full system did not perform consistently due to issues with motor torque, load handling, and integration. However, the project demonstrates the intended interaction flow and system design.`

## 18.2 What Works Well
- `1. App control and command-based interaction works reliably
2. Gate mechanism using stepper motor functions as intended
3. Overall mechanical system (lever, pulley, structure) works well
4. Overall concept and interaction flow is clear and understandable`

## 18.3 What Still Needs Improvement
- `1. Motor system is not strong enough to handle the load consistently
2. Power and driver setup needs better optimization
3. Full system integration and synchronization between stages
4. Better alignment of pulley and platform to reduce resistance and jamming
5. More reliable sensor behavior (IR stability and accuracy)
6. Improved structural balance to support weight distribution (especially for wheels and movement)
7. Simplification of control flow to reduce dependency on multiple manual triggers`

## 18.4 What Changed From the Original Plan
How did the project change from the initial idea?

**Response:**  
`The initial idea was to create a fully automated catapult system where all stages—gate opening, rewind, detection, and release—would happen smoothly in a single sequence with minimal user input.
During development, the project evolved due to practical challenges with motor performance, load handling, and power supply. The system required more manual control through the app, and stages like rewind and release had to be triggered separately rather than running seamlessly.
There were also changes in components, such as replacing the DC motor with a NEMA stepper motor in an attempt to improve torque and control. Structural adjustments were made to the platform and pulley system to improve movement and alignment.
Overall, the project shifted from a fully automated system to a semi-controlled interactive system, focusing more on demonstrating the sequence and interaction rather than achieving perfect automation.`

---

# 19. Reflection

## 19.1 Team Reflection
What did your team do well?  
What slowed you down?  
How well did you manage time, tasks, and responsibilities?

**Response:**  
`The project was handled mostly individually, which helped maintain consistency across mechanics, electronics, and coding. Since all parts of the system were closely connected, working on everything together made it easier to make quick decisions and iterate without dependency on others. A lot of progress came from hands-on experimentation, testing components directly, and learning through trial and error.
What slowed things down was time management and late integration. Many components, especially motors and electronics, were brought together towards the end, which made debugging more difficult and limited the time available for proper testing. Earlier planning and prioritising critical systems like motor performance and power setup would have improved the overall workflow. Dividing time better between building, testing, and debugging would have made the process smoother.`

## 19.2 Technical Reflection
What did you learn about:
- electronics,
- coding,
- mechanisms,
- fabrication,
- integration?

**Response:**  
`This project helped in understanding how electronics, coding, and mechanical systems work together in a real setup rather than in isolation. Working with motors, drivers, and power systems showed how important torque, voltage, and current are, especially when dealing with load. It became clear that even if components work individually, they may not perform the same when integrated.
On the coding side, writing stage-based logic, handling app inputs, and integrating sensors was a useful learning experience. It also highlighted how hardware limitations directly affect software behavior. Fabrication and mechanisms were interesting to work on, especially combining lever motion with a pulley system to create a controlled action.
Overall, the biggest learning was how complex integration is, and how small issues in one part of the system can affect the entire workflow.`

## 19.3 Design Reflection
What did you learn about:
- designing for play,
- delight,
- clarity,
- physical interaction,
- player understanding,
- iteration?

**Response:**  
`The project showed that designing for play is not just about having an interesting idea, but about how clearly the interaction is understood by the user. Even though the concept was simple, the sequence of actions made it more engaging by adding anticipation and control.
It also became clear that too many steps or controls can confuse the user, especially when the system is not fully automated. Simplifying the interaction and reducing unnecessary steps would improve clarity. Physical interaction, such as moving the system and aiming, added an extra layer of engagement and made the experience more hands-on.
Iteration played a major role throughout the process, as multiple changes were made to both the structure and logic to improve how the system worked and felt.`

## 19.4 If You Had One More Week
What would you improve next?

**Response:**  
`With more time, the main focus would be on improving the motor and power system to make the launch sequence more reliable and consistent. This would include selecting better drivers, optimizing voltage supply, and reducing load on the mechanism.
I would also simplify the control flow so that the system runs more automatically instead of relying on multiple manual inputs. Earlier and more structured testing would be a priority, especially for load handling, motor performance, and full system integration.
Additionally, improvements in alignment, sensor stability, and overall finishing would help make the system more stable and user-friendly, resulting in a smoother and more polished experience.`

# 20. Final Submission Checklist

Before submission, confirm that:
- [x] Team details are complete
- [x] Project description is complete
- [x] Inspiration sources are included
- [x] Player journey is written
- [x] Sketches are added
- [x] BOM is complete
- [x] Purchase list is complete
- [x] Budget summary is complete
- [x] Mechanical planning is documented if applicable
- [x] App planning is documented if applicable
- [x] Code flowchart is added
- [x] Task breakdown is complete
- [x] Weekly logs are updated
- [x] Risk register is complete
- [x] Testing log is updated
- [x] Playtesting notes are included
- [x] Build photos are included
- [x] Final reflection is written

---

# 21. Suggested Repository Structure

```text
project-repo/
├── README.md
├── images/
│   ├── concept-sketch.jpg
│   ├── labeled-sketch.jpg
│   ├── circuit-diagram.jpg
│   ├── ui-mockup.jpg
│   ├── prototype-1.jpg
│   └── final-build.jpg
├── code/
│   ├── main.py
│   ├── test_code.py
│   └── notes.md
├── cad/
│   ├── models/
│   └── screenshots/
└── docs/
    ├── references.md
    └── extra-notes.md
```

---

# 22. Instructor Review

## 22.1 Proposal Approval
- [ ] Approved to proceed
- [ ] Approved with changes
- [ ] Rework required before proceeding

**Instructor comments:**  
`[Instructor fills this section]`

## 22.2 Midpoint Review
`[Instructor fills this section]`

## 22.3 Final Review Notes
`[Instructor fills this section]`

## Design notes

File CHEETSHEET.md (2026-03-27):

# GitHub Cheat Sheet
## Open Design and Technology Final Project

This file is a quick guide for working in your project repository.

---

# 1. First setup

## Fork this repository
1. Click **Fork**.
2. Rename your fork using this format:

`ODT-2026-TeamName`

### Example
`ODT-2026-PixelWizards`

## Do not do this
- Do not keep the default repo name.
- Do not upload everything at the very end.
- Do not delete headings from the main `README.md`.

---

# 2. Folder structure

Your repository should look like this:

```text
project-repo/
├── README.md
├── CHEATSHEET.md
├── images/
├── code/
├── cad/
└── docs/
```

## What goes where

| Folder | What to put inside |
|---|---|
| `images/` | Sketches, photos, screenshots, UI mockups, circuit diagrams |
| `code/` | Main code files, test code, code notes |
| `cad/` | CAD files, STL files, design exports, screenshots |
| `docs/` | Extra notes, reference links, playtest notes |

---

# 3. Uploading files

## Upload an image
1. Open the repository.
2. Open the `images` folder.
3. Click **Add file**.
4. Click **Upload files**.
5. Drag your image into the browser.
6. Scroll down and click **Commit changes**.

## Upload code
1. Open the `code` folder.
2. Click **Add file**.
3. Click **Upload files**.
4. Upload your `.py`, `.ino`, `.txt`, or `.md` files.
5. Click **Commit changes**.

## Good file names
Use clean file names such as:
- `concept-sketch.jpg`
- `ui-mockup.png`
- `prototype-v1.jpg`
- `main.py`
- `ble-test.py`

## Avoid bad file names
Avoid names like:
- `IMG_4587.jpg`
- `finalfinalrealone.png`
- `new code latest.py`

---

# 4. Adding Images to your README

**Rule #1:** You must upload your image file to the `images/` folder *before* you can link it in the README. 
**Rule #2:** File names are case-sensitive. `Image.JPG` is not the same as `image.jpg`.

I have placed a file called `sample.jpg` in your `images/` folder. Copy and paste the 4 examples below into your README to see how they work!

---

### Example 1: The Basic Image (Markdown)
Use this for a standard, full-size image.

```md

```

### Example 2: Resizing an Image (HTML)
Phone photos are often massive. If an image takes up your whole screen, switch to HTML to control the width. *(Change `width="400"` to whatever number looks best).*

```html
<img src="images/sample.jpg" width="400">
```

### Example 3: Centering an Image
If you want your documentation to look clean and professional, you can center the image on the page using this HTML block.

```html
<p align="center">
  <img src="images/sample.jpg" width="400">
</p>
```

### Example 4: Side-by-Side Images
Want to show the front and back of your build, or your app next to your hardware? Just put two HTML image tags on the exact same line with a space between them. 

```html
<img src="images/sample.jpg" width="300"> <img src="images/sample.jpg" width="300">
```

*(Note: Ensure their combined width is less than ~800 so they fit next to each other on most screens).*

---

### Quick Troubleshooting: "My image is just showing a broken link icon!"
If your image doesn't load when you click the **Preview** tab, check these 3 things:
1. **Path:** Did you include `images/` before the file name?
2. **Spelling/Spaces:** Does the code match your file name exactly? (Avoid spaces in file names—use dashes `-` instead).
3. **Extension:** Did you write `.png` but the file is actually a `.jpg`?
# 5. Editing README

## To edit the README directly on GitHub
1. Open `README.md`.
2. Click the pencil icon.
3. Add or update your content.
4. Scroll down.
5. Write a short commit message.
6. Click **Commit changes**.

## Update this file every week
You should keep updating:
- task status,
- BOM,
- sketches,
- testing logs,
- playtesting notes,
- photos,
- weekly progress.

---

# 6. Creating folders on GitHub

GitHub does not create truly empty folders, so a folder is usually created by making a file inside it. [web:54][web:58]

## To create a folder from the GitHub website
1. Click **Add file**.
2. Click **Create new file**.
3. Type a path like:

```text
images/.gitkeep
```

4. Commit the change.

You can do the same for:
- `code/.gitkeep`
- `cad/.gitkeep`
- `docs/.gitkeep`

Typing a file path with a `/` is the usual way to create a folder in GitHub’s web interface. [web:54][web:57]

---

# 7. Commit message guide

Use short commit messages that explain what changed.

## Good examples
- `Added BOM and budget`
- `Uploaded concept sketch`
- `Updated week 2 progress`
- `Added BLE test code`
- `Uploaded final prototype photos`

## Bad examples
- `update`
- `stuff`
- `changes`
- `final`

---

# 8. Team workflow

## Suggested rule
At the end of every class, do these 4 things:
1. Upload new photos.
2. Update task status.
3. Add what worked and what failed.
4. Commit changes before leaving class.

## Team habit
One person can lead the build update for the day, but both team members are responsible for checking that the repo stays current.

---

# 9. If you make a mistake

## If you uploaded the wrong file
- Upload the correct file.
- Delete the wrong file.
- Write a clear commit message.

## If you deleted something important
- Tell your teammate immediately.
- Check the file history.
- Restore it from an earlier version if needed.

## If your README looks broken
- Check for missing `#`, `|`, or backticks.
- Preview before committing.

---

# 10. Minimum expectation each week

By the end of each week, your repository should show visible progress.

## Week 1
- Idea
- Sketch
- Inspiration
- BOM
- Task plan

## Week 2
- Tests
- CAD or structure progress
- Code or app progress
- Photos

## Week 3
- Integrated prototype
- Technical debugging
- Gameplay/playtesting notes

## Week 4
- Final build
- Final documentation
- Reflection
- Clean repo

---

# 11. Final reminder

This repository is not just a place to submit work.

It is:
- your project tracker,
- your evidence of process,
- your design notebook,
- your technical log,
- your final documentation.

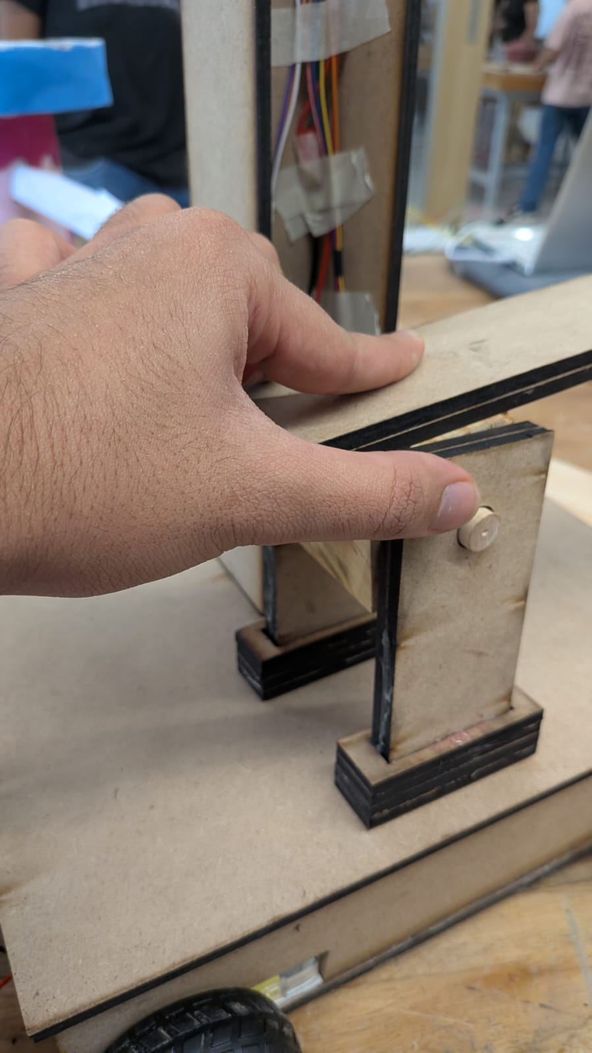
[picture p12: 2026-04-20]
images/hinge and mechanism.jpeg

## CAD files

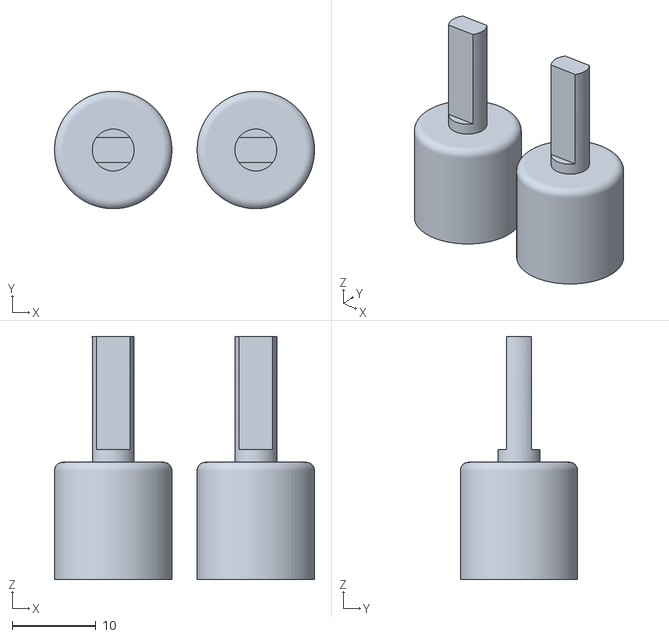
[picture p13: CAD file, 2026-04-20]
cad/Abhinav Axel Caps.stl
31.0 x 14.0 x 29.0

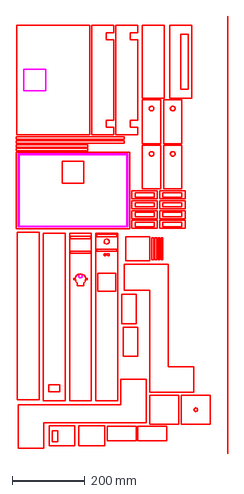
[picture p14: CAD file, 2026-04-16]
cad/Abhinav_ODT_Laser Cut_Body_ components.dxf
578.6 x 1200.0 mm

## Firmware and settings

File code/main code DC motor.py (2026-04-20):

from applink import AppInventorLink
from machine import Pin, PWM
import time

app = AppInventorLink()

# stepper (gate)
IN1 = Pin(21, Pin.OUT)
IN2 = Pin(19, Pin.OUT)
IN3 = Pin(18, Pin.OUT)
IN4 = Pin(5, Pin.OUT)

# LEDs
green = Pin(13, Pin.OUT)
red = Pin(12, Pin.OUT)

# DC motor (PWM)
in3 = PWM(Pin(26), freq=1000)
in4 = PWM(Pin(27), freq=1000)

# IR sensor
ir = Pin(15, Pin.IN)

# state
last_command_time = time.ticks_ms()
timeout = 200
current_action = "stop"

calibrated = False
drop_triggered = False
close_triggered = False
gate_open = False

rewind_active = False
unwind_active = False

# stepper sequence
step_seq = [
    [1,0,0,0],
    [0,1,0,0],
    [0,0,1,0],
    [0,0,0,1]
]

step_index = 0

#  STEPPER 
def step_forward():
    global step_index
    s = step_seq[step_index]
    IN1.value(s[0]); IN2.value(s[1]); IN3.value(s[2]); IN4.value(s[3])
    step_index = (step_index + 1) % 4

def step_backward():
    global step_index
    step_index = (step_index - 1) % 4
    s = step_seq[step_index]
    IN1.value(s[0]); IN2.value(s[1]); IN3.value(s[2]); IN4.value(s[3])

def stepper_stop():
    IN1.value(0); IN2.value(0); IN3.value(0); IN4.value(0)

def move_angle(angle, speed):
    global step_index
    steps = int(angle * 512 / 360 * 4)
    direction = 1 if steps > 0 else -1
    steps = abs(steps)

    for _ in range(steps):
        step_index = (step_index + direction) % 4
        s = step_seq[step_index]
        IN1.value(s[0]); IN2.value(s[1]); IN3.value(s[2]); IN4.value(s[3])
        time.sleep(speed/1000)

#  DC MOTOR 
def motor_ccw():
    in3.duty(512)
    in4.duty(0)

def motor_cw():
    in3.duty(0)
    in4.duty(512)

def motor_stop():
    in3.duty(0)
    in4.duty(0)

#  APP 
def handle_app_request(params):
    global last_command_time, current_action
    global calibrated, drop_triggered, close_triggered
    global rewind_active, unwind_active

    action = params.get("action")
    print("App:", action)

    if action == "done":
        calibrated = True
        stepper_stop()
        green.value(1)
        return {"status": "locked"}

    if action == "drop":
        if calibrated:
            drop_triggered = True
        return {"status": "drop"}

    if action == "close":
        if calibrated:
            close_triggered = True
        return {"status": "close"}

    if action == "rewind":
        rewind_active = True
        unwind_active = False
        return {"status": "rewind"}

    if action == "unwind":
        unwind_active = True
        rewind_active = False
        return {"status": "unwind"}

    if action == "stop_motor":
        rewind_active = False
        unwind_active = False
        motor_stop()
        return {"status": "stopped"}

    if calibrated:
        return {"status": "locked"}

    last_command_time = time.ticks_ms()
    current_action = action
    return {"status": action}

app.start_ap("CATAPULT", "12345678")
app.on_request(handle_app_request)

green.value(0)
red.value(0)
motor_stop()
stepper_stop()

# MAIN LOOP 
while True:
    app.process()
    now = time.ticks_ms()

    # Stage 0–1: Manual gate setup
    if not calibrated:

        if current_action == "left":
            step_backward()
            red.value(1)
            green.value(0)
            time.sleep(0.003)

        elif current_action == "right":
            step_forward()
            green.value(1)
            red.value(0)
            time.sleep(0.003)

        else:
            red.value(0)
            green.value(0)

        if time.ticks_diff(now, last_command_time) > timeout:
            current_action = "stop"
            stepper_stop()

    else:

        # DROP → full automatic sequence
        if drop_triggered and not gate_open:

            move_angle(-90, 2)
            stepper_stop()
            gate_open = True

            # rewind until IR
            while ir.value() == 1:
                motor_ccw()
                red.value(1)
                time.sleep(0.2)
                red.value(0)

            motor_stop()

            # release for 5 sec
            start = time.time()
            while time.time() - start < 5:
                motor_cw()
                green.value(1)
                time.sleep(0.2)
                green.value(0)

            motor_stop()
            drop_triggered = False

        # CLOSE gate
        if close_triggered and gate_open:
            motor_stop()
            move_angle(90, 2)
            stepper_stop()
            gate_open = False
            green.value(1)
            close_triggered = False

        #  MANUAL MOTOR CONTROL 

        if rewind_active:
            if ir.value() == 1:
                motor_ccw()
                red.value(1)
            else:
                motor_stop()
                rewind_active = False
                red.value(0)

        elif unwind_active:
            motor_cw()
            green.value(1)

        else:
            motor_stop()
            red.value(0)
            green.value(0)

    time.sleep(0.001)

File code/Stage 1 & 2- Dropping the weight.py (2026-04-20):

from applink import AppInventorLink
from machine import Pin
import time

app = AppInventorLink()

# GATE STEPPER
IN1 = Pin(21, Pin.OUT)
IN2 = Pin(19, Pin.OUT)
IN3 = Pin(18, Pin.OUT)
IN4 = Pin(5, Pin.OUT)

#  LEDs 
green = Pin(13, Pin.OUT)
red = Pin(12, Pin.OUT)

#  DC MOTORS 
m1a = Pin(26, Pin.OUT)
m1b = Pin(33, Pin.OUT)

m2a = Pin(32, Pin.OUT)
m2b = Pin(25, Pin.OUT)

#  STATE 
last_command_time = time.ticks_ms()
timeout = 200
current_action = "stop"

calibrated = False
drop_triggered = False
gate_open = False

#  STEPPER SEQUENCE 
step_seq = [
    [1,0,0,0],
    [0,1,0,0],
    [0,0,1,0],
    [0,0,0,1]
]

step_index = 0

def step_forward():
    global step_index
    seq = step_seq[step_index]
    IN1.value(seq[0])
    IN2.value(seq[1])
    IN3.value(seq[2])
    IN4.value(seq[3])
    step_index = (step_index + 1) % 4

def step_backward():
    global step_index
    step_index = (step_index - 1) % 4
    seq = step_seq[step_index]
    IN1.value(seq[0])
    IN2.value(seq[1])
    IN3.value(seq[2])
    IN4.value(seq[3])

def stepper_stop():
    IN1.value(0)
    IN2.value(0)
    IN3.value(0)
    IN4.value(0)


def move_angle(angle, speed):
    global step_index

    steps = int(angle * 512 / 360 * 4)
    direction = 1 if steps > 0 else -1
    steps = abs(steps)

    led_toggle = False

    for _ in range(steps):
        step_index = (step_index + direction) % 4
        step = step_seq[step_index]

        IN1.value(step[0])
        IN2.value(step[1])
        IN3.value(step[2])
        IN4.value(step[3])

       
        if led_toggle:
            green.value(1)
            red.value(0)
        else:
            green.value(0)
            red.value(1)

        led_toggle = not led_toggle

        time.sleep(speed/1000)

    
    green.value(0)
    red.value(0)

#  MOTOR CONTROL 
def motors_forward():
    m1a.value(1); m1b.value(0)
    m2a.value(1); m2b.value(0)

def motors_stop():
    m1a.value(0); m1b.value(0)
    m2a.value(0); m2b.value(0)

#  APP HANDLER 
def handle_app_request(params):
    global last_command_time, current_action, calibrated, drop_triggered

    action = params.get("action")
    print("App:", action)

    if action == "done":
        calibrated = True
        current_action = "stop"
        stepper_stop()
        green.value(1)   # 🟢 stays ON
        red.value(0)
        print("Calibration locked")
        return {"status": "locked"}

    if action == "drop":
        if calibrated:
            drop_triggered = True
            print("Drop triggered")
        return {"status": "drop"}

    if calibrated:
        return {"status": "locked"}

    last_command_time = time.ticks_ms()
    current_action = action

    return {"status": action}

#  INIT 
app.start_ap("CATAPULT", "12345678")
app.on_request(handle_app_request)

print("System ready")

green.value(0)
red.value(0)
motors_stop()
stepper_stop()

#  MAIN LOOP 
while True:
    app.process()

    now = time.ticks_ms()

    #  STAGE 0 
    if not calibrated:

        if current_action == "left":
            step_backward()
            red.value(1)     #LEFT led
            green.value(0)
            time.sleep(0.003)

        elif current_action == "right":
            step_forward()
            green.value(1)   # RIGHT led
            red.value(0)
            time.sleep(0.003)

        else:
            # idle
            red.value(0)
            green.value(0)

        if time.ticks_diff(now, last_command_time) > timeout:
            current_action = "stop"
            stepper_stop()
            red.value(0)
            green.value(0)

    # -------- STAGE 1 & 2 --------
    else:

        if drop_triggered:

            if not gate_open:
                print("Stage 1 ready")
                time.sleep(1)

                print("Stage 2 opening gate")

                move_angle(-90, 2)   #blinking

                stepper_stop()
                print("Gate opened")

                gate_open = True

                # start motors after drop
                motors_forward()

            else:
                print("Gate already open")

            drop_triggered = False

    time.sleep(0.001)
